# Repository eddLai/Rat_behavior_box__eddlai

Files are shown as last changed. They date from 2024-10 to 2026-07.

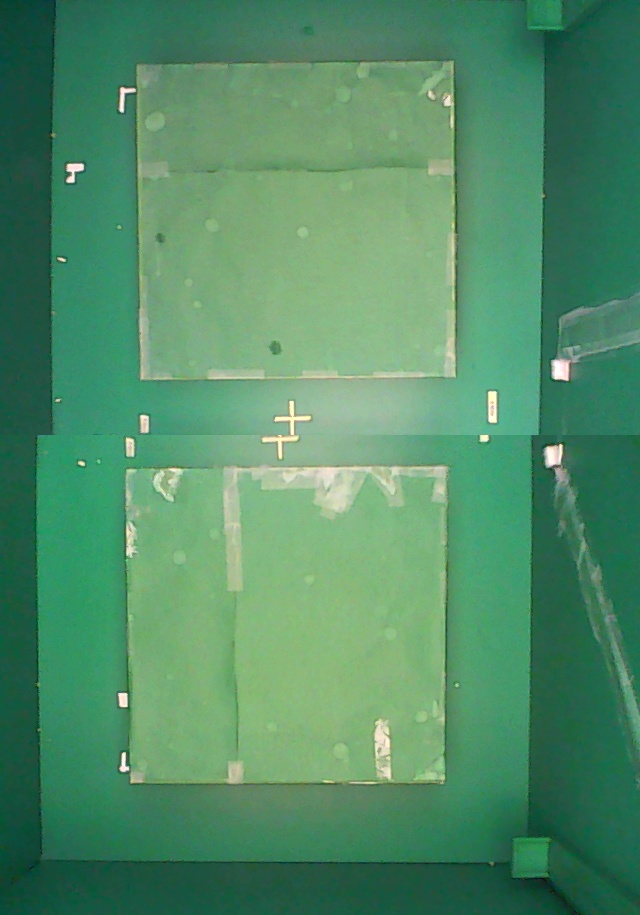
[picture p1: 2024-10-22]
python_to_detect_rat_at_point/baseline/82.jpg

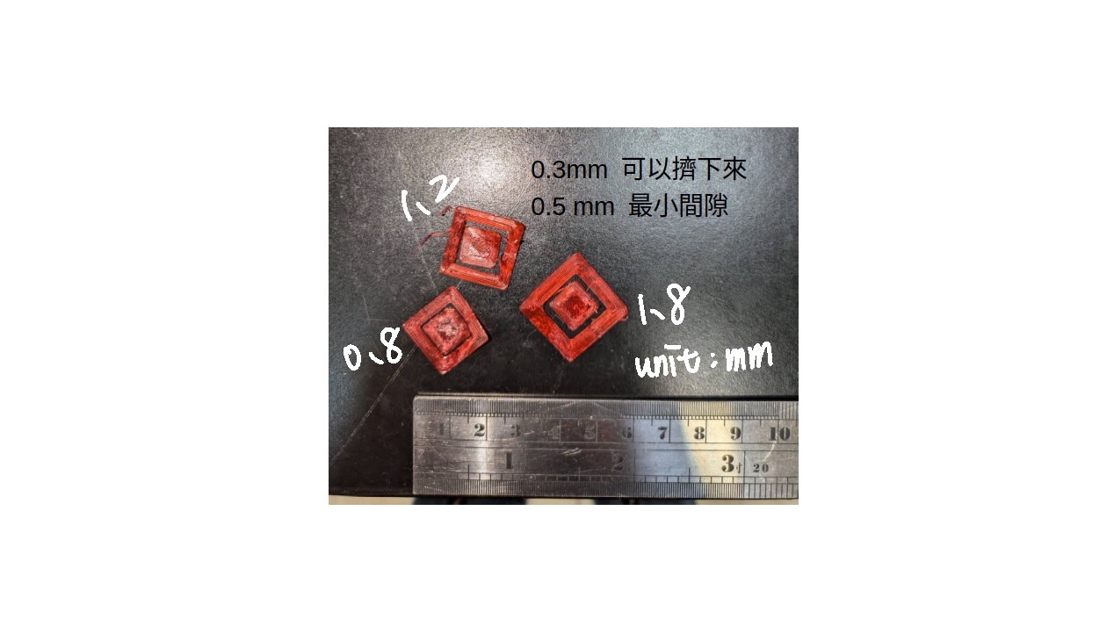
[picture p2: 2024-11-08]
behavior_box_3Dprint_models_eddlai/precision.jpg

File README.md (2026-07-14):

## Now Operating Version...
- **Arduino for Cue and Reward**: [`UART_left_right_dir_deter_v8.ino`](Arduino_UART_from_python/UART_left_right_dir_deter_v8/UART_left_right_dir_deter_v8.ino)
- **Camera for Rat Position**: [`python_to_detect_rat_at_point/two_camera_videos_diff_Uart_blah.py`](python_to_detect_rat_at_point/two_camera_videos_diff_Uart_blah.py)
---

# Arduino UART 版本演進說明

## 版本功能比較總表

| 版本 | 主要功能 | 獎勵控制方式 | LED閃爍方式 | 重要修正 |
|---|---|---|---|---|
| **v2** | 基礎左右/直立模式 | 繼電器 (relay) | 阻塞式 (blocking) | 基礎版本 |
| **v3** | 新增正確回應判斷 | 繼電器 (relay) | 阻塞式 (blocking) | 修正獎勵邏輯 |
| **v4** | 非阻塞式處理 | 繼電器 (relay) | 非阻塞式 (non-blocking) | 解決延遲問題 |
| **v5** | 伺服馬達版本 | 360伺服馬達 (servo) | 非阻塞式 (non-blocking) | 硬體更新 |
| **v6** | 純左右轉模式 | 360伺服馬達 (servo) | 非阻塞式 (non-blocking) | 移除模式選擇 |
| **v7** | 三向閥與純手動控制 | 180伺服馬達 (servo) | 非阻塞式 (non-blocking) | (1)平滑步進控制三向閥+齒輪開關 (2)新增修改起身模式、手動控制模式、排水模式 |
| **v8** | 新增長距離移動/純轉向模式 | 180伺服馬達 (servo) | 非阻塞式 (non-blocking) | (1)新增 Mode 5：碰 L/R 直接給水，黑點 `D` 作為 rearm 防重複 (2)全部字串改用 `F()` 巨集釋放 SRAM (3)記憶體不足，暫時註解停用 Mode 2 |

---

## 詳細版本說明

### v2 - 基礎版本
**檔案位置**: `Arduino_UART_from_python/UART_left_right_dir_deter_v2/`

**主要功能**:
- Mode 1: 攝影機偵測模式 (Camera detection mode) - 左右轉任務
- Mode 2: 站立模式 (Standup mode) - 隨機間隔給水 (20-35秒)

**硬體配置**:
- 獎勵控制: 繼電器 (reward_L: pin 6, reward_R: pin 7)
- LED: L1/L2 (pin 11/10), R1/R2 (pin 13/12)

**已知問題**:
- LED閃爍期間會阻塞其他指令處理
- 不論走對走錯都給水

**獨立衍生檔案**:
- `blah_altertime.ino`: 新增模式3 (固定時間間隔的站立模式)
- `blah_correct_reward.ino`: 新增正確回應判斷 (只有走對邊才給水)

---

### v3 - 正確回應判斷版本
**檔案位置**: `Arduino_UART_from_python/UART_left_right_dir_deter_v3/`

**新增功能**:
- Mode 1: 攝影機偵測模式 (Camera detection mode) - 左右轉任務
- Mode 2: 站立模式 (Standup mode) - 隨機間隔給水 (20-35秒)
- Mode 3: 固定時間間隔站立模式 (Standup fixed mode) - 可手動設定固定時間間隔給水
- ✅ 判斷大鼠是否走對邊，只有正確才給水
- ✅ 新增狀態變數: `isObstacle_L`, `isObstacle_R`, `taskInProgress`
- ✅ 新增獎勵時間控制: `reward_time = 3500ms`

**核心改進**:
- 接收 'L' 或 'R' 訊號時會檢查是否與任務方向 (`ans`) 一致
- 走錯邊會重置狀態但不給水
- 新增 `resetState()` 函數統一管理狀態重置

**仍存在的問題**:
- LED閃爍仍為阻塞式，可能導致指令延遲

---

### v4 - 非阻塞式處理版本
**檔案位置**: `Arduino_UART_from_python/UART_left_right_dir_deter_v4/`

**核心改進**:
- ✅ **非阻塞式LED閃爍**: 使用 `millis()` 和狀態機實現
- ✅ **訊號緩衝處理**: 即使在閃爍中也能立即處理指令
- ✅ 新增 `processResponse()` 函數獨立處理每個指令

**技術細節**:
```cpp
// 非阻塞閃爍相關變數
bool blinking = false;
unsigned long blinkLastToggle = 0;
int blinkCount = 0;
int blinkState = 0;
const int maxBlinks = 15;
```

**執行流程改善**:
1. `left_right()` 中先累積所有指令進 buffer
2. 使用 `processResponse()` 逐一處理
3. LED閃爍與指令處理並行，不會互相阻塞

**解決的問題**:
- ✅ 解決 "如果在紅點下待太久會出現觸發LED CUE錯誤的問題"
- ✅ 避免閃爍時 L/R 指令被讀走但無法處理

---

### v5 - 伺服馬達版本
**檔案位置**: `Arduino_UART_from_python/UART_left_right_dir_deter_v5/`

**硬體更新**:
- ✅ **獎勵系統**: 從繼電器改為伺服馬達 (因直流抽水馬達對電壓值敏感)
  - `reward_L`: Servo on pin 10 (角度 114° 給水, 90° 停止)
  - `reward_R`: Servo on pin 9 (角度 60° 給水, 90° 停止)
- ✅ **獎勵時間縮短**: `reward_time = 300ms` (v3/v4 為 3500ms)
- ✅ **LED pin腳調整**: L1/L2 (pin 12/13), R1/R2 (pin 6/7)

**Mode 3 功能更新**:
- Mode 3 改為手動控制LED測試模式
- 接收 '1' 指令: LED閃爍10秒
- 接收 '0' 指令: LED關閉

**程式碼變化**:
```cpp
// v4使用繼電器
digitalWrite(reward_L, LOW);  // 激活
digitalWrite(reward_L, HIGH); // 停止

// v5使用伺服馬達
reward_L.write(114);  // 激活
reward_L.write(90);   // 停止
```

---

### v6 - 純左右模式版本 (為排除 50Hz 雜訊)(但實測無效:P)
**檔案位置**: `Arduino_UART_from_python/UART_left_right_dir_deter_v6/`

**核心改進**:
- ✅ **移除模式選擇**: 開機自動進入 Mode 1（左右轉任務）
- ✅ **即插即用**: 按 reset 鍵或接上行動電源立即啟動
- ✅ **精簡程式碼**: 移除 Mode 2/3 相關程式碼
- ✅ **獨立供電友善**: 不需連接電腦選擇模式，適合使用行動電源

**使用情境**:
- Arduino 改用行動電源供電，避免電腦 USB 雜訊干擾
- 不需要透過 MobaXterm 選擇模式
- 專注於左右轉任務實驗

**與 v5 的差異**:
```cpp
// v5: 需要等待模式選擇
while (Serial.available() == 0) {
  // 等待用戶輸入 '1', '2', '3'
}

// v6: 直接啟動
Serial.println("Camera detection mode (left-right task) started automatically");
```

---

### v7 - 三向閥開關門與純手動控制版本
**檔案位置**: `Arduino_UART_from_python/UART_left_right_dir_deter_v7/`

**核心改進與硬體更新**:
- ✅ **180度三向門控制**: 取代原本的 360 度連續旋轉馬達，改用 180 度伺服馬達控制實體三向門 (`posClose = 0`, `posOpen = 180`)。
- ✅ **平滑步進控制 (`moveServoSmooth`)**: 為了減少機構震動與噪音，所有開關門動作皆改為每 10ms 移動 2 度的平滑步進，大幅提升硬體作動穩定性與動物實驗品質。
- ✅ **馬達防抖優化**: `attach()` 與 `detach()` 邏輯完美整合於模式切換與各功能中，並加入起訖點判斷，消除待機時的雜訊與抖動。
- ✅ **緊急停止 (`D`) 安全升級**: 收到 `D` 時，兩側門會平滑強制關閉，並確實重置當前位置記憶 (`currentPosL/R`)。

**重構&更新模式**:
- **Mode 1 (左右轉任務)**: 保留核心邏輯，走對邊時平滑開門給水後關門。
- **Mode 2 (自動站立)**: 移除水泵控制，改為僅開啟「右門」並維持 6 秒，隨機間隔 20~35 秒。
- **Mode 3 (改成手動控制開關)**: 徹底移除舊版不直覺的秒數輸入。改為「純手動發球機」：
  - 輸入 `1`: 右門打開，LED 持續閃爍 (給水)。
  - 輸入 `0`: 右門關閉，LED 立即熄滅。
- **Mode 4 (新增：Drain Mode)**: 實驗後的專屬管路清洗/排水模式。
  - 輸入 `O`: 雙門全開。
  - 輸入 `C`: 雙門關閉。
  - 提示可隨時重啟序列埠來回到主選單。

---

### v8 - 長距離移動模式與記憶體 (SRAM) 優化版本
**檔案位置**: `Arduino_UART_from_python/UART_left_right_dir_deter_v8/`

**核心改進**:
- ✅ **新增 Mode 5 (Long locomotion / pure turning)**: 適用於長距離移動與純轉向任務。
  - 碰到 `L` 點 → 平滑開左門給水後關門；碰到 `R` 點 → 平滑開右門給水後關門。
  - **與 Mode 1 的差異**: 不需 `M` 觸發、不指定方向、不判斷對錯 —— 碰到就給。
- ✅ **Mode 5 防重複機制 (`armed` 狀態鎖)**: 解決「老鼠只觸發一次，馬達卻反覆開關多次」的問題。
  - 根因：Python 端是逐幀送訊號，老鼠停在 L/R 點時會連續灌入大量 `L`/`R`，每個字元都觸發一次給水。
  - 解法：用單一共用鎖 `armed`。給一次水後立即上鎖 (`armed = false`)，阻塞給水期間湧入的重複訊號全部忽略；**必須走過任一黑點（收到 `D`）才重新武裝** (`armed = true`)，才能再給下一次。
  - 初始 `armed = true`，第一次碰 L/R 即給水。此設計逼老鼠實際跑完路線（黑點→L/R）才有獎勵，符合 locomotion 實驗本意。
  - Arduino 端相容既有 Python：三個黑點 (MD/LD/RD) 都送 `D`，任一個都可 rearm。
- ✅ **SRAM 記憶體優化（關鍵修正）**: 所有 `Serial.print/println` 字串改用 `F()` 巨集包裝。
  - 問題：加入 Mode 5 後全域變數用到 **2047/2048 bytes (99%)**，開機時 stack 與全域變數相撞 → **選單完全印不出來、系統無反應**。
  - 解法：`F("...")` 讓字串留在 Flash（32KB，充裕）而非複製到 SRAM（僅 2KB）。行為與輸出完全不變，只是搬移儲存位置。

**⚠️ Mode 2 (自動站立) 暫時停用**:
- 因 ATmega328P 的 SRAM 僅 2KB，為釋放記憶體空間，先將 `stand_up()` 函式及 `loop()` 內的 Mode 2 分支**註解掉**。
- 開機選單仍列出 `Enter '2'`，但該模式功能尚未啟用。

**Mode 對照表 (v8)**:
| Mode | 功能 | 說明 |
|---|---|---|
| 1 | 攝影機偵測（左右轉） | 需 `M` 觸發、判斷對錯，走對邊才給水 |
| 2 | ~~自動站立~~ | ⚠️ 暫時停用（記憶體不足） |
| 3 | 手動控制 | 輸入 `1` 開右門+閃燈、`0` 關門 |
| 4 | 排水 (Drain) | 輸入 `O` 雙門全開、`C` 雙門關閉 |
| 5 | 長距離移動 / 純轉向 | 碰 `L`/`R` 直接給水，黑點 `D` 作為 rearm |

---

# Others
3D tracker
- official doc when behavior box be setup: [[3DTracker Doc for v180924 (under refinement).pdf]]
- [3DTracker-FAB documentation — 3DTrackerFAB-doc documentation](https://3dtrackerfab.readthedocs.io/en/latest/)

---
# 《需求列表》

### 直立式給水器｛站立｝
1. 針對每次水量限制問題+鼠鼠會扒上去/電線被3D tracker抓到難濾掉的問題
  - sol1. 把馬達架高、深度變深、上面也要做高擋起來
2. 瀑布自助餐問題
  - sol2. 中繼出水孔（鼠鼠舔的地方）深度挖深一點（？）可以小小裝水、累積到某個水量再流掉
  - sol3. 換材質

3. 給水時間random除錯困難的問題
  - sol4. 新增輸入mode 2時間，改Arduino

### 掛勾式給水平台｛左右｝
1. 鼠鼠頭上線會勾到方形轉角的問題
  - sol5. 把平台改半圓（包含底部也是弧狀）
  - sol6. 把平台改高一點，增加鼠鼠底下通過空間
2. 鼠鼠選錯邊依舊會給reward的殘水問題
  - sol7. 直接改code，把紅點以外的其他點作為判斷是否走對邊的檢查點，判斷正確才出水
3. 出水針頭因為各種水壓阻塞底座不穩導致需一直調整的問題
  - sol8. 印一個針頭固定座

### 銅網上的線路
1. 線路時常接觸不良的問題
  - sol9. 焊起來一勞永逸（嗎
  - sol10. 應歪歪要求封裝起來
  - sol11. 更新乖乖、改善風水佈局
  - sol12. 3D列印鼠鼠女神像祭壇

### 其他
1. LED燈會不定時左右亂閃
  - sol13. 改善code
  - sol14. 買更多乖乖
2. 忘記這是指什麼了XD👇
  - 可以定義順序，改python

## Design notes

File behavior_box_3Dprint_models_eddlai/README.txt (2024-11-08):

我使用2020年買的ender 3S v2中國製列印機
tinmorry, yasin等中國耗材就夠用了
列印品質跟線材的濕度比較有關係。
PETG需要非常注意平台的調平，在列印的繞圈階段就要確認

├─Cura slicing setting
│      creality_base_extruder_0_petg_15may_tz
│      creality_ender3s1_petg_15may_tz
│      PETG setting.curaprofile
│      PLA setting.curaprofile
│
├─One-way Door and LED shell
│      Door holders RL.gcode
│      Door pillar.gcode
│      Door.gcode
│      Door_all.gcode
│      led shell and One-way Door.shapr
│      LED shell.gcode
│
└─Rat_watering_platform
    │  trunk v2.gcode
    │  wall.gcode
    │  water slide.gcode
    │  water supply platform v2.shapr
    │  water supply platform v2.stl
    │
    └─old version
            main water supply platform.gcode
            upper water supply platform.gcode
            WALL_water supply platform.gcode

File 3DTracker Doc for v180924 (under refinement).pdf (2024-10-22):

## 3DTrackerFAB documentation

3DTrackerFAB-doc
- 1. Hardware preparation
– | 1.1. Cameras
– | 1.2. Extension cables
– | 1.3. PC
– | 1.4. Camera mounting
- 2. Software preparation
– | 2.1. Installing 3rd party libraries
– | 2.2. Installing main programs of the 3DTracker-FAB
- 3. Calibrator and recorder usage
– | 3.1. Camera calibration using the Calibrator
– | 3.2. Recording 3D video using the Recorder
- 4. Preprocessor usage
- 5. Tracker usage
– | 5.1. Starting the Tracker
– | 5.2. Importing and setting parameters
– | 5.3. Fitting
– | 5.4. Saving and Exporting the fitting result
– | 5.5. Measurement tools
- 6. Other software usage
– | 6.1. Viewer
– | 6.2. Data analysis scripts (Python/MATLAB)
- 7. Trouble shooting
– | 7.1. Calibrator/Recorder does not start (with R200 cameras)
– | 7.2. Calibration does not work well
– | 7.3. Objects or animals are not captured
– | 7.4. Dropping frames during recording
– | 7.5. Menu bar invisible / mouse offset from view
- 8. Information for developers
– | 8.1. Preparing the development environment
– | 8.2. Programming Style
– | 8.3. More Information
- 9. Appendix
– 9.1. R200 camera mechanism

– | 9.2. Details of the parameters in the Tracker
– | 9.3. Output files
– | 9.4. Synchronizing with other systems
– | 9.5. Online tracking (under development)

## 3DTracker-FAB documentation¶

The document was written by Dr. Jumpei Matsumoto and Dr. Marcelo Aguilar-Rivera. We thank Dr. Laleh Quinn for her proof reading. This version is still under refinement.

## Introduction¶

The 3DTracker-FAB (for animal behavior) is an open source software for 3D-video based computerized behavioral analysis. The 3DTracker-FAB will help users acquire and analyze 3D trajectories of animal body parts, as shown below.

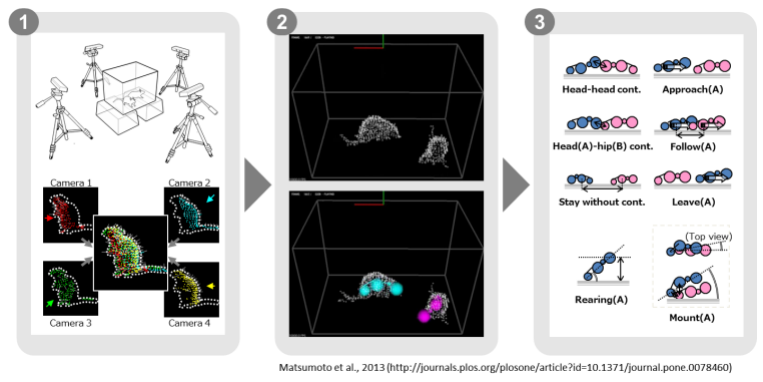
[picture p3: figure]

[Fig 0-1]

First, animals 3D imagines are reconstructed from depth cameras (~4) images (Fig 0, left). Second, body positions are estimated by fitting skeletal models to the 3D image (Fig 0, middle). Third, several behavioral parameters are calculated based on body part trajectories (Fig 0, right).

In the current workflow, a set of software modules are used. The images from multiple cameras are calibrated and recorded, with the “Calibrator” and “Recorder” modules respectively (Chapter 3). Then, the recorded images from different cameras are processed off-line for their integration into a full 3D image, down sampling, etc., with the “Preprocessor” module (Chapter 4). Then, the skeletal models are fitted to the 3D image, with the “Tracker” module (Chapter 5). Finally, the resultant 3D trajectories (csv file format) are analyzed with Python/MATLAB scripts (Chapter 6). The present version of the 3DTracker-FAB only supports the analysis of rats and mice. Other species could be supported in the future.

The 3DTracker-FAB is basically licensed under an MIT license. So, note that the software is provided “as is”, without warranty of any kind, express or implied.

### 1. Hardware preparation¶

### 1.1. Cameras¶

Multiple Intel Realsense R200 or D400 cameras (Fig 1-1) are required for recording with the 3DTracker system. These cameras are chosen because of their outstanding performance characterized by the lack of interference among cameras when multiple units are simultaneously capturing the same object (see Appendix for details of the camera). A R200 or D400 is composed of a color camera and a depth sensor to obtain RGB and depth images, respectively.

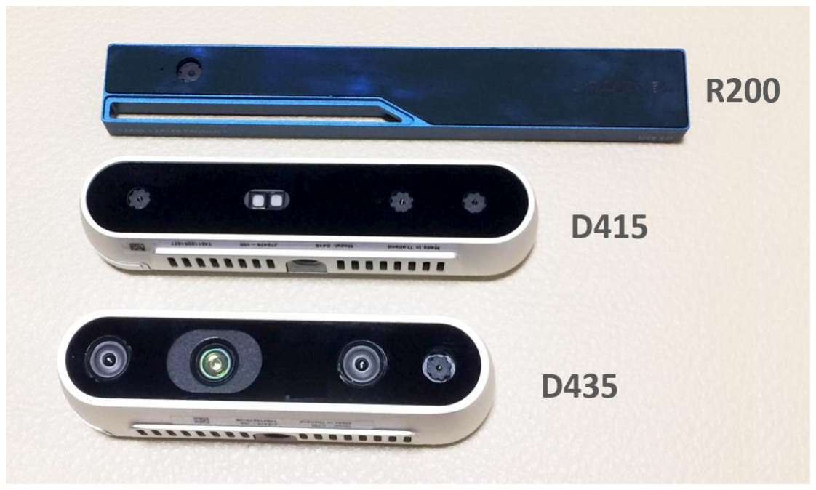
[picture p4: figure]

[Fig 1-1: Intel realsense cameras]

You can get R200 and D400 from the Intel website:

https://click.intel.com/realsense.html

D400 has two models: D415 and D435. The software supports both of them. For new users, we recommend using D400, because it is an improved version of R200. Both D435 and D415 are good enough for tracking with the present system. For the detailed comparison, see: https://realsense.intel.com/compare/

### 1.2. Extention cables¶

Given that the original USB 3.0 cable of the R200 or D400 is too short, it is necessary to extend it or to replace with a longer cable. We have confirmed the following extentions/cables work:

- For R200:
– UGREEN, USB 3.0 Active Extension Cable (https://www.amazon.com/dp/B01FQ88CE6)
- For D400:
– | Anker, PowerLine 10ft USB-C to USB 3.0 (https://www.anker.com/products/variant/powerline-10ft-usb-c-to-usb-3-0/A8167011)
– | NewNex, UL-A01C12-8M (https://www.newnex.com/usb-3-1-type-c-active-cable-legacy.php)

### 1.3. PC¶

The 3DTracker (except for MATLAB/Python scripts) runs only on Windows 10 (64-bit). The CPU does not need to be very fast. However, the number of cores (number of parallel processers) in the CPU should be more than the number of cameras used, because the Recorder software processes each camera data in parallel. In addition, a large HDD should be installed in the PC, because of the big size of 3D video. The PC monitor resolution should be more than 1280x1024. We have been recording from four cameras with a HP EliteDesk 800 G2 Core i7-6700 (3.4 GHz), 8GB RAM, 500 GB + 6TB HDD, and a power unit of 400W 80PLUS.

The camera uses almost the whole transmission bandwidth of an USB 3.0 port. So, more than one camera cannot be connected to the same USB controller. For this reason, we added three expansion cards
(https://www.amazon.co.jp/dp/B00B6ZCNGM) to get in total four USB controllers (including the one embedded in the mother board), thus having a camera connected per controller. The expansion cards have to be hooked to the PC power supply to feed enough power into the “active” USB extension cable, beside of be inserted in the mother board slots.

Note

We strongly recommend using the same components suggested above to get a high-quality signal. We have tried several different products and those previously described are the best ones based on our experience.

### 1.4. Camera mounts¶

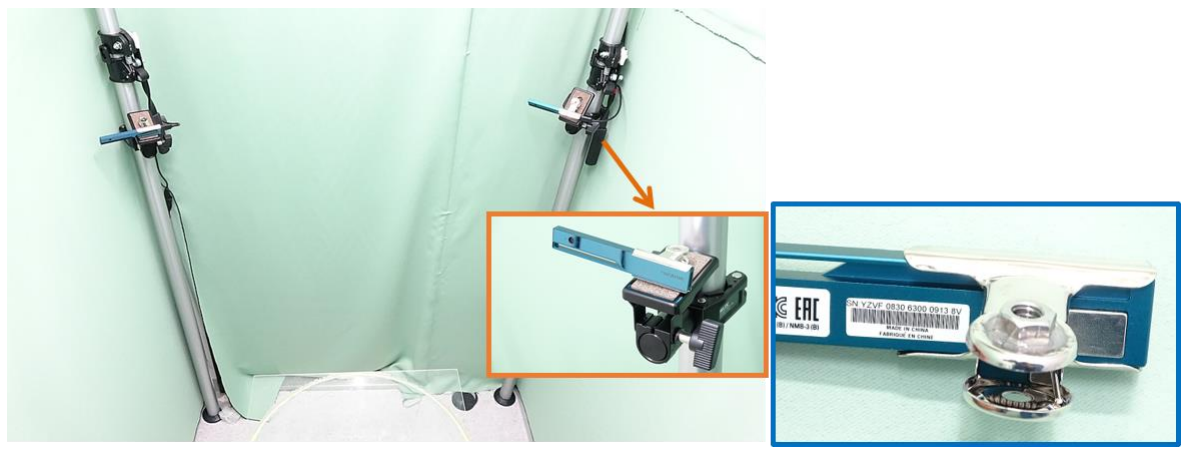
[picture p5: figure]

[Fig 1-2]

Example of four depth cameras setup. Each R200 camera was hooked to a post fixed to the floor and the ceiling (insert orange frame), through a custom adaptor made by gluing a 1/4-inch nut to a metal bulldog clip (insert blue frame). The main picture shows two of the four cameras.

Hint

The depth sensor of the camera measures the depth by emitting infrared (IR) light and capturing the IR reflection to objects (see Appendix for the detail of the mechanism of the camera). So, two cameras should not be placed face-to-face, to prevent the infrared sensor from saturating because of directly received infrared light from the other. Similarly, shiny surfaces should not be placed in front of a camera. Thus, we recommend placing the cameras slightly tilted downward from the horizontal plane. Also check the camera specification for 1) the minimum distance between the camera and objects for depth sensing (e.g., 40 cm for R200), and 2) the field of view. These constraints should be considered during camera setting.

### 2. Software preparation¶

### 2.1. Installing 3rd party libraries¶

The 3DTracker-FAB utilizes functions of many free software libraries. Please download and install the software below. You can download the software from our website at http://3dtracker.org/downloads.html

1. OpenCV 3.2.0 (library for image processing)
2. PCL 1.8.0 (library for point cloud processing)
3. Visual C++ 2015 redistributable (library for running the software that was written on Visual Studio C++ 2015)
4. Kinect for Windows Runtime v1.8 (library for Kinect v1 camera and backward compatibility)

Warning

DO NOT install the R200 driver provided by Intel because the 3DTracker doesn’t need it. Also, some users have reported that updating the R200 firmware could trigger the malfunctioning of the R200. See links below:

https://github.com/IntelRealSense/librealsense/issues/163https://github.com/IntelRealSense/librealsense/issues/429

After installing the libraries listed above, add the following folder to the environment variable “PATH”:

- C:\opencv320\build\x64\vc14\bin (change “C:\opencv320”, to your install directory)
- C:\Program Files\PCL 1.8.0\bin
- C:\Program Files\OpenNI2\Redist

See how to add directories to the “PATH”: https://www.computerhope.com/issues/ch000549.htm

### 2.2. Installing main programs of the 3DTracker-FAB¶

Download the prebuilt version of the 3DTracker-FAB from our website http://3dtracker.org/downloads.html

Uncompress the downloaded zip file. The extracted folder contains the software and data folder.

Hint

Because recorded data will be initially saved in the data folder, it is recommended to place the extracted data folder in a large HDD.

### 3. Calibrator and recorder usage¶

The Calibrator and the Recorder are modules for calibration and recording of the multiple-cameras setup of the 3DTracker system, respectively.

### 3.1. Camera calibration using the Calibrator¶

The video instruction: https://youtu.be/IE_ZDVuzYC8

Calibration for the relative positions of the cameras are necessary for integrating images captured by different cameras and then to re-construct a full 3D image. The Calibrator is a software wizard for the multi-camera calibration.

Connect the cameras to the PC and start Calibrator.exe. If Calibrator.exe doesn’t start, the cameras may have not been recognized (see Trouble shooting). In the start page (step 0) of this software wizard, you will see a 3D view display (center) where camera images are projected as a cloud of points, and a wizard window (bottom). In the 3D view, the red, green, and blue arrows correspond to X, Y, and Z axes, respectively. The 3D view can be controlled with the right button (R) dragging of a mouse, as follows: R + drag -> Rotate the view; R + drag + Ctrl key -> Zoom in and out; R + drag + Shift key -> translate the view. To discriminate clearly between the points from different cameras, you can color the points by enabling “Mark cameras with different colors” in the top left window. The 3D view can be switched to the 2D view where the image of each camera is shown, by clicking the “Switch to 2D” button on the top left window. Click “Next” in the wizard window to proceed to the next step.

In the step 1, move cameras to cover the space where you want to record while checking the 2D view. Also select the reference camera (the point clouds of the other camera will be aligned to the one of the reference camera). Note that in the 2D view, camera images are ordered in left-to-right and top-to-bottom according to the camera IDs.

In the following steps (2-6), the user scans the recording space with a light pointer and records the pointer track. Then, the software calculates the relative camera positions fitting the observed trajectories recorded from the different cameras during the calibration process (Fig 3-1, left). For the pointer we recommend using incandescent MAG-LITE (e.g., https://www.amazon.com/dp/B00002N9ET) in the candle mode, by removing the lid covering the light bulb (Fig 3-1, right)

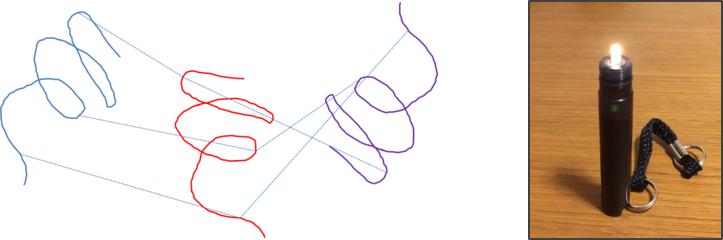
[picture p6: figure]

[Fig 3-1: left, schematic showing the mechanism. The lines with different colors represent the pointer trajectories observed simultaneously from 3 different cameras in this example; right, light pointer as a candle]

In the step 2, set the camera exposure for pointer tracking. Put the pointer in the recording space and turn off the room light. Then, set the exposure using the slider in the wizard window, to enhance the contrast between the pointer light and the background.

In the step 3, Set the brightness threshold for the pointer detection and tracking.

In the step 4, slowly move the pointer in the recording space to draw a trajectory for calibration (a spiral trajectory is recommended). Note that the pointer should be in view of all the cameras.

In the step 5, filter the trace (to remove some noise). You can use the temporal trimming and the outlier removal to remove the noise in the traces. For the detail of the parameters of the outlier removal, see: http://pointclouds.org/documentation/tutorials/statistical_outlier.php.

In the step 6, first, check if the point clouds from different cameras are perfectly aligned. To check the alignment, place some objects in front of the cameras and color the points by enabling “Mark cameras with different colors” in the top left window. Then, look at the corners and the overall shapes of the objects in the screen. If point clouds with different colors are not well aligned, go back to the previous steps and repeat the operation described above until a good result is achieved.

The calibration using the pointer is only for the relative positions among cameras. So, the absolute position of one of the cameras (the reference camera) should be input manually. Move the sliders in the wizard window to set the position and the rotation of the reference camera. Set X axis rotation, Y axis rotation, Z axis rotation, and translation. Rotation after translation makes it hard to adjust the position and rotation (see also the video link above). When you set the absolute position, make sure that the Y axis corresponds to the vertical axis, because the Tracker assumes it for fitting purposes.

Lastly, in the step 7, set the region of interest (ROI) with the sliders. You can also input the value directly by clicking + Ctrl key on slider. Then, click “Next” and “Save Config and Quit”, to finish the calibration.

### 3.2. Recording 3D video using the Recorder¶

Start Recorder.exe. Once the Recorder starts, the following screen will appear:

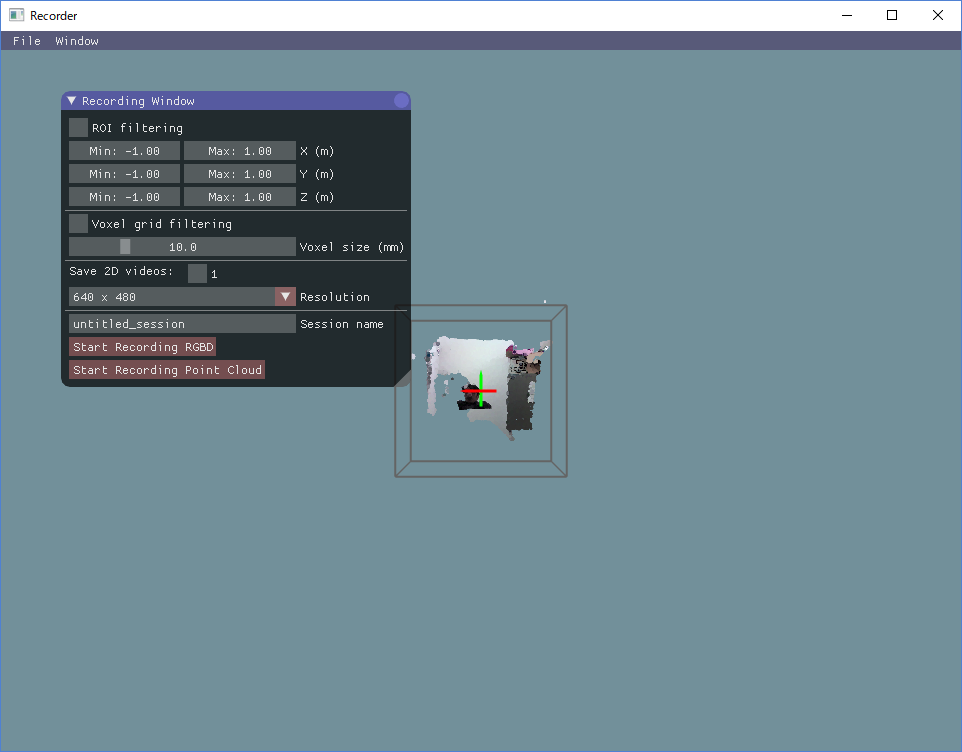
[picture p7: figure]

[Fig 3-2]

You will see a menu-bar, and a 3D view display which is same as the one in the Calibrator (see above). The various tool windows can be displayed from the menu tab > ‘Window’.

To start recording, in the “Recording window”, input the data file name in the “session name” text box and click “Start recording RGBD” or “Start Recording Point cloud” button. With “Start recording RGBD”, raw data consisting of RGB images and depth (D) images is stored. The size of the raw data is big (around 300 MB/camera/min). With “Start Recording Point cloud”, the point cloud data captured from the cameras are stored. Combined with the “ROI filtering” which removes the points outside the ROI, and “Voxel grid filtering” which down samples the points, the size of the point cloud data becomes much smaller than that of the raw RGBD data. Use 5 and 10 mm for the voxel size for the voxel grid filtering for mice and rats, respectively. By enabling the “save 2D videos” check boxes for the cameras, you can also save the 2D RGB video, which is useful for tracking (see Chapter 5), preliminary visual observation of behavior, etc. If you choose recording the raw data (RGBD), you can generate the 2D video offline. So, in this case, it is recommended not to check those boxes to reduce the computational load during recording.

Note

For D400 cameras, in addition to point cloud and RGBD file format, recording with rosbag file format (http://wiki.ros.org/rosbag) is also supported. Using the format, you can select higher spatial and temporal resolution, although the file size will be large (the compression algorithm in rosbag format is faster but less efficient than the one in RGBD format). Click “Start Recording Bag” in the “Recording window” for the rosbag recording. Before the preprocessing (Chapter 4), convert the rosbag to RGBD format, by using Rosbag2RGBD.exe.

After starting recording, 3D view is disabled and an RGB image is shown instead, reducing the computational load during recording. Click “Stop” button to stop recording. The recorded data is stored in the “data” folder containing the Recorder app (“Recorder.exe”) in the folder named as the “session name” that you have input before recording. See Chapter 9 for details about the output files.

### 4. Preprocessor usage¶

This module is for preprocessing the recorded data, for merging the 3D point clouds, down sampling (removing overlapping points) the data, calculating the surface normal vector at each point, etc. The preprocessing is necessary for pose estimation in the Tracker (Chapter 5). When you start the Preprocessor, it asks to select a folder to processes the session data in. If you select a folder containing multiple sub-folders from different sessions, the module will process the data in these sub-folders if they don’t contain additional sub-levels. This is because the app does not search more than one level below the folder selected. The data preprocessed previously is skipped by default. The Preprocessor is called from the command prompt, and the preprocessing parameters are set by command line. We have prepared the following batch files that call the Preprocessor with certain predefined parameters as follows:

- Preproc_rat.bat: Use this for rats (down sampling voxel size = 10 mm).
- Preproc_rat(f).bat: Same as the previous one but it does not skip the data already preprocessed.
- Preproc_mice.bat: Use this for mice (down sampling voxel size = 5 mm).
- Preproc_mice(f).bat: Same as Preproc_rat(f), but for mice.

Example of a command line (Advanced):

> preprocessor.exe -f -2dvid -vsize 0.01 -camuse 0011

- -f: no skip for the data preprocessed previously
- -2dvid: generate 2D video files from RGBD data
- -vsize: down sampling voxel size (in meters)
- -camuse: selects cameras for the merging of the point clouds. 0=not use, 1=use.

In the example above, the merging points cloud is generated by using images from the camera #3 and #4.

### 5. Tracker usage¶

### 5.1. Starting the Tracker¶

Start the Tracker and select the xml file in the data folder that you want to analyze. Then, the following screen will appear.

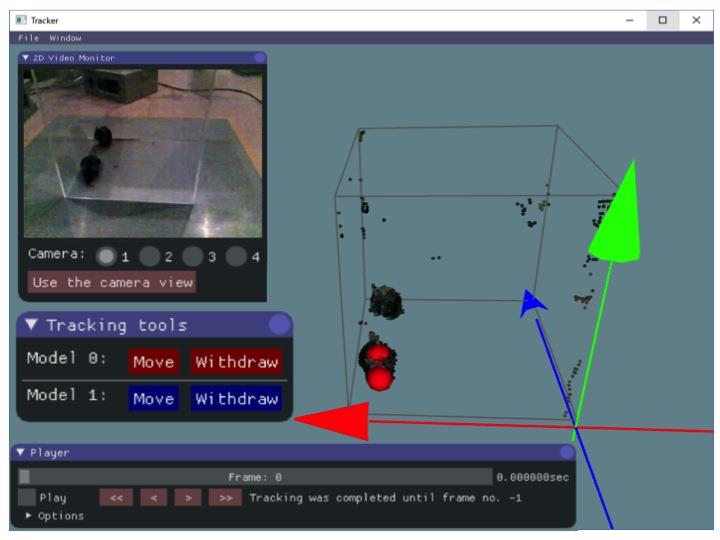
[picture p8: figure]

[Fig 5-1]

The windows on the screen are those you can launch by clicking the tabs in the menu Window. In addition, the skeletal models represented by connected spheres are shown in the Tracker screen. The 3D view can be controlled with the right button (R) by dragging the mouse as follows: R drag -> Rotate the view; R drag + Ctrl key -> Zoom in and out; R drag + Shift key -> translate the view.

The following “Player window” is used for searching a video frame and fitting execution.

[Fig 5-2]

The numbers inside, and at the right side of the top slide bar, indicate the current # of the video frame and time, respectively. You can move the slide bar to search a specific video frame. By checking the box “Play” you can start the playback. The fitting of the skeleton models for pose estimation during playback is for the frames where it was not estimated. For the frames where it has already been estimated, the result of fitting is shown. The progress during the fitting process is displayed as “Tracking that has been completed…”. When starting the fitting process, you have to do it from the first frame and then continue with the next one. DO NOT skip frames during the fitting since it can result in an irreversible corrupted physic simulation.

### 5.2. Importing and setting parameters¶

Before starting the fitting, you need to set some parameters for the process. The default parameters (e.g., dimensions of a skeletal model) are optimized for rats. So, to analyze mice, import predefined parameters for mice (e.g., Track_params_mouse_v20171104.xml) from “File Menu > Import params”. The parameters can be displayed and modified with the “Model Editor window”, “Physics sim params window”, “ROI setting window”, and “Color filter window”.

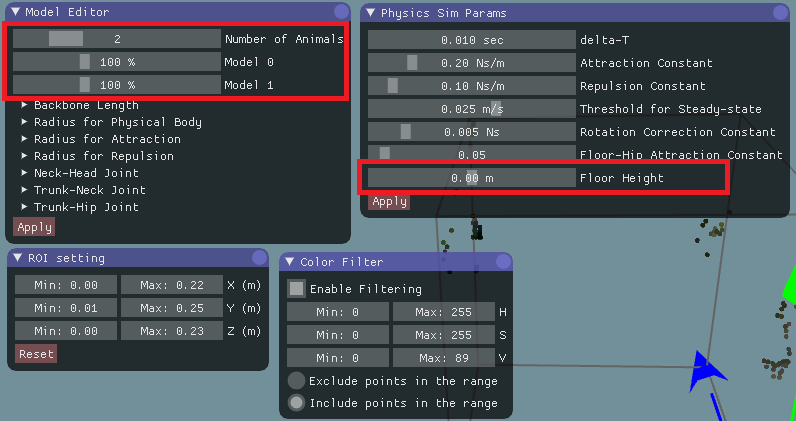
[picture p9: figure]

[Fig 5-3]

The “Model Editor window” is for the skeletal models. The slider on the top defines the number of animals (skeletal models). The scale of an animal can change depending on its age, sex, etc. So, you may need to change the scales using the other sliders in the red rectangle as shown in Fig 5-3. Detailed parameters outside the red rectangle (e.g., “Backbone Length”, “Radius for Physical Body”, etc.) don’t need to be changed frequently. After changing the parameters in the “Model Editor window”, click “Apply” button on the bottom, to apply the change.

The “Physics sim params window” is to parametrize the fitting algorithms, and usually it is necessary to change just some of them. The value of the “floor height” should be set to the height of the floor where the animal is standing in the global coordinate system. This parameter is important to constrain the movement of the model. The details of the parameters mentioned above are described in Chapter 9.

“ROI setting window” and “Color filter window” can be used to remove the points of non-animal objects. Removing such points will help fitting the skeleton models to the points cloud. In the color filtering, set the range of colors to include/exclude in the HSV color space (https://en.wikipedia.org/wiki/HSL_and_HSV). These parameters could be repeatedly used for the same experimental setup regarding rodent strain, age, apparatus, etc. You can re-use the parameters by exporting and then importing them from the “File menu > Export params” and “File menu > import params”, respectively.

### 5.3. Fitting¶

After the parameters have been set, start the fitting. Note that you cannot change the parameters during the fitting, otherwise the fitting will be re-initialized. In the first frame, manually set the initial position of the skeletal models. With shift key pressed, click two points from hip to head. You will see a line like the one in the figure below.

[Fig 5-4]

If it is hard to know the direction of the subject in a 3D view, try using “2D video monitor window” as shown in Fig 5-1. Then, click the “Move” button in “Tracking tools window” to change the skeleton model to the correct place (Fig 5-5).

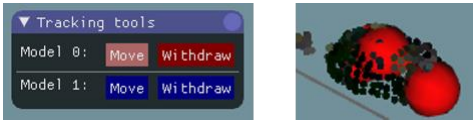
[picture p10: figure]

[Fig 5-5]

The model is automatically fit from the initial position. If you find that the model was not fitted properly, manually adjust it by dragging body parts (sphere) of the model with the left mouse button. After placing the skeleton models, start the fitting process by enabling the “Play” check box in the “Player window”. The positions shown during the play are the result of the fitting process. As the fitting progresses, when you find an error in fitting, such as when a big part of a model is outside the 3D image, reversed direction, or swapping between animals (Fig 5-6), pause the fitting by disabling the “Play” check box.

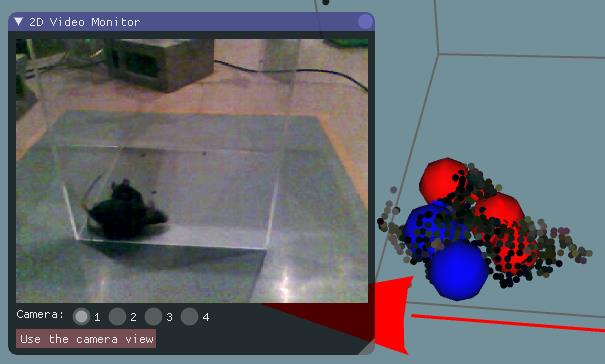
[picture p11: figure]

[Fig 5-6: an example of swapping error]

Then, by clicking “<<”, “<”, “>”, and “>>” buttons in the “Player window”, go back to the frame when the models start to get the error (Fig 5-7, middle). Then, manually adjust the models by dragging body parts (Fig 5-7, right) and re-start fitting from that frame by enabling “Play” check box.

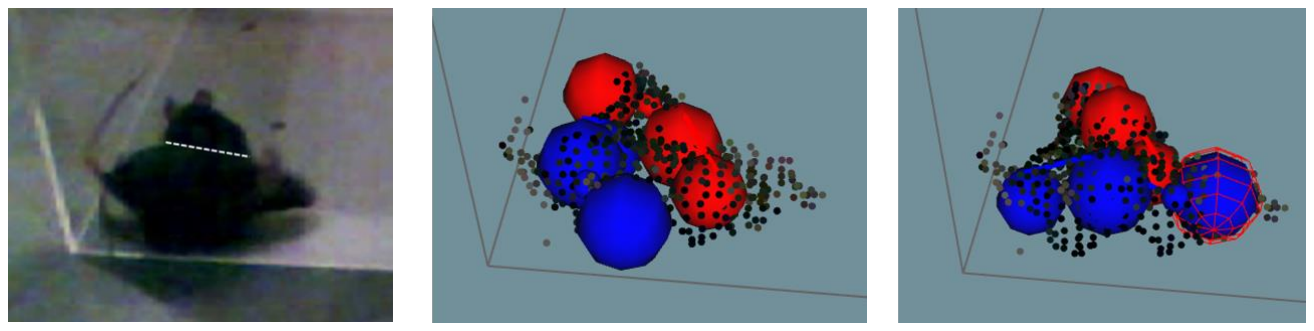
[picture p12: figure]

[Fig 5-7: correction of the swapping error shown in Fig. 5-6. Left: Actual mice positions, middle: before correction, right: after correction.]

If you find an error again, pause and fix it following the instructions described above. Repeat it and then progress with the fitting up to the last frames.

Hint

The Tracker has many functions to support this semi-automatic fitting process:

- The speed of playback can be changed in “Option” in the “Player window”.
- “Play” check box can be switched by pressing the space key.
- By rotating the mouse wheel during the video pausing you can change the video frame.
- By rotating the mouse wheel during playback it changes the playback speed.

Note

The fitting process must be done without skipping frames to get a successful result. Even if you don’t have an animal in the first frame, start from the first frame and not from the frame when the animal appears. For the fitting during the absence of animals, you can withdraw the model with “Withdraw” button in “Tracking tools window”. Note that the fitting process will be skipped if you move the frame using the slider on the top of the “Player window” or “<<”, “<”, “>”, or “>>” button below. When you restart the fitting after the manual correction, make sure that it restarts from the frame that you have corrected (check the progress of fitting in “Tracking has been completed…” display).

### 5.4. Saving and Exporting the fitting result¶

Once you have finished the fitting, you can re-check the result by playback or moving the slider in the “Player window”. The fitting result won’t be changed just by replaying the frames. You can save the fitting result from “File menu > Save result”. The result will be automatically loaded the next time you open the data. You can also reset the results to the one saved last time from “File menu > Load result”. This save/load function is also useful to interrupt the work. For the data analysis on the trajectories

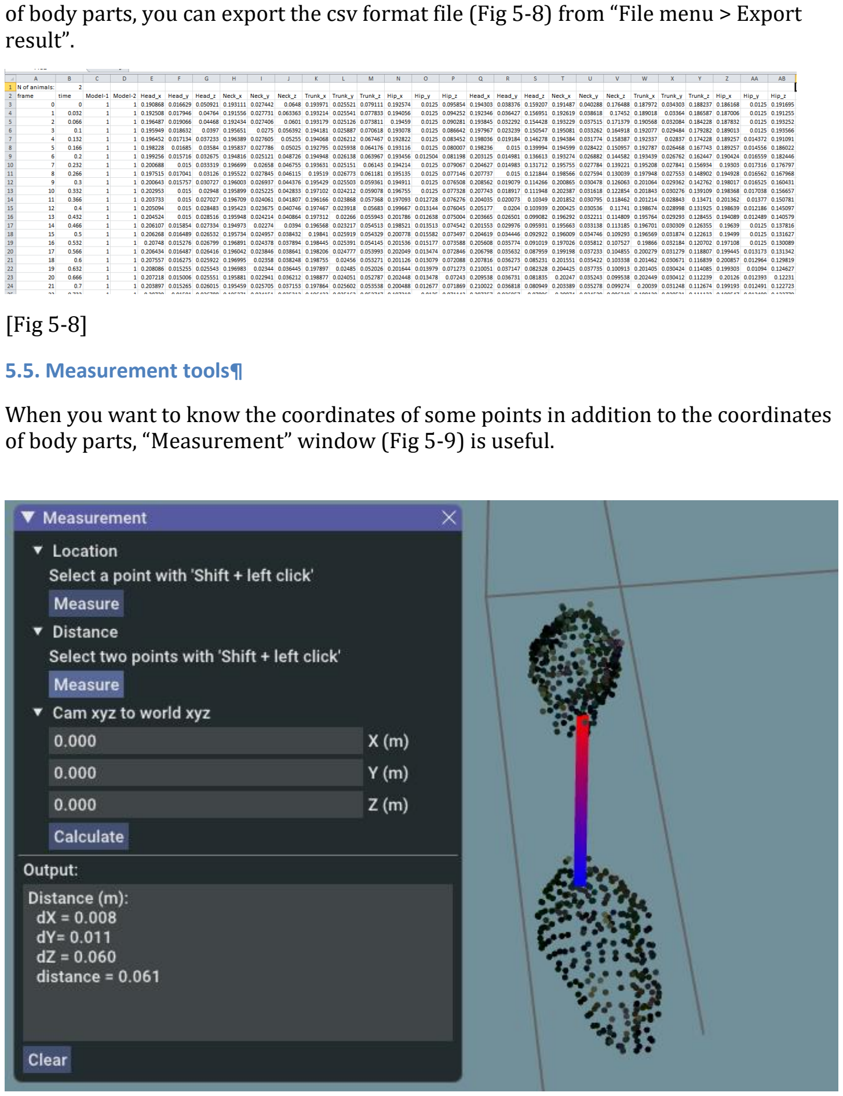
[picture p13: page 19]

of body parts, you can export the csv format file (Fig 5-8) from “File menu > Export result”.

[Fig 5-8]

### 5.5. Measurement tools¶

When you want to know the coordinates of some points in addition to the coordinates of body parts, “Measurement” window (Fig 5-9) is useful.

[Fig 5-9: Measurement tools. In this example, the distance between manually selected two points (a nose of a mouse and a hip of another mice) is calculated.]

The tool can be used to estimate three types of data: (1) location, this is the coordinate of a selected point, (2) distance between two selected points, and (3) an absolute coordinate converted from a relative coordinate to a camera.

For (1) and (2), select point(s) and click the “Measure” button, then the result will appear in the “Output” text box.

For (3), input the relative coordinate in the text boxes and click the “Calculate” button, then the result will appear in the “Output” text box. This function is useful, for example, when you want to know the coordinate of another sensor (microphone, high-speed camera, 4K camera, etc) mounted on the 3D cameras. If you input (X, Y, Z) = (0, 0, 0), you can also know the camera positions.

### 6. Other software usage¶

### 6.1. Viewer¶

The software can be used as a viewer to check the recorded data but without the fitting functions. To open the data in the Viewer, no pre-processing is necessary.

### 6.2. Data analysis scripts (Python / MATLAB)¶

We provide Python and MATLAB scripts for various processing with the trajectory data (csv file) and raw 3D video data (point cloud data, RGBD data) in the following site:

https://github.com/ThreeD-Tracker-FAB/3DTrackerFAB-script

We also encourage people to share their own scripts. You can do it through our github site, the forum (https://groups.google.com/forum/#!forum/3dtracker) or by contacting us through the form for such purpose (http://3dtracker.org/contact.html). If you have a useful code you would like to share, please let us know!

### 7. Trouble shooting¶

If you cannot find a specific topic associated to the 3DTracker or the solution for some related issue, ask your question in our forum (https://groups.google.com/forum/#!forum/3dtracker).

### 7.1. Calibrator/Recorder does not start (with R200 cameras)¶

The camera may not be recognized by the PC. Rule out any possible issue associated with cables between the PC and the camera. Check the connectors at the camera is not damaged.

Re-check the connection of the camera according to Chapter 2. If the problem persists, check whether the camera is listed in the “Device manager” (Fig 7-1).

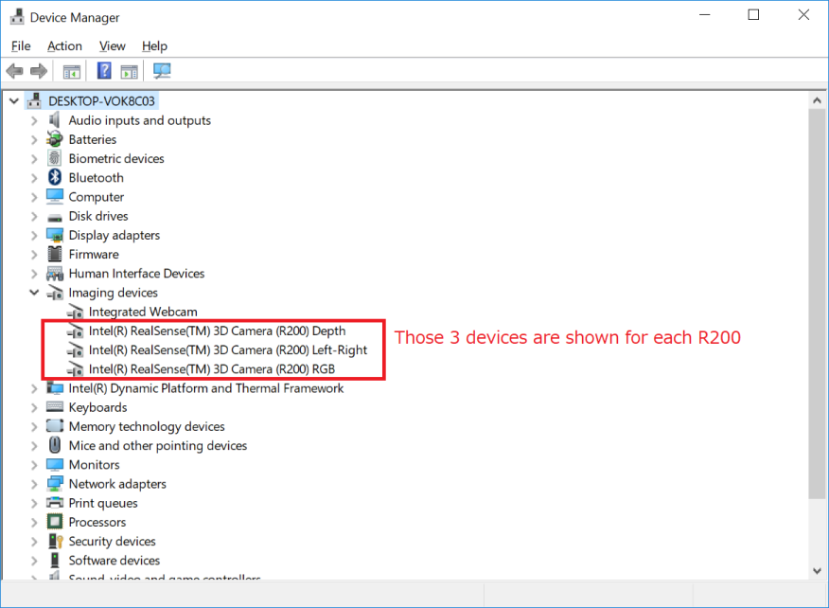
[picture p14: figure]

[Fig 7-1]

If the camera is not listed, make sure that “USB selective suspend” is disabled (https://www.techsupportalert.com/content/how-fix-annoying-windows-usb-problem.htm). (https://www.techsupportalert.com/content/how-fix-annoying-windows-usb-problem.htm) If the camera is listed but the problem persists, uninstall the device of RGB camera and re-install it by clicking “scan for hardware changes” icon (Fig 7-2). It has been reported that an RGB camera driver error happens after “Windows 10 Creators Update”, and the steps above fix the problem. (https://github.com/IntelRealSense/librealsense/issues/481).

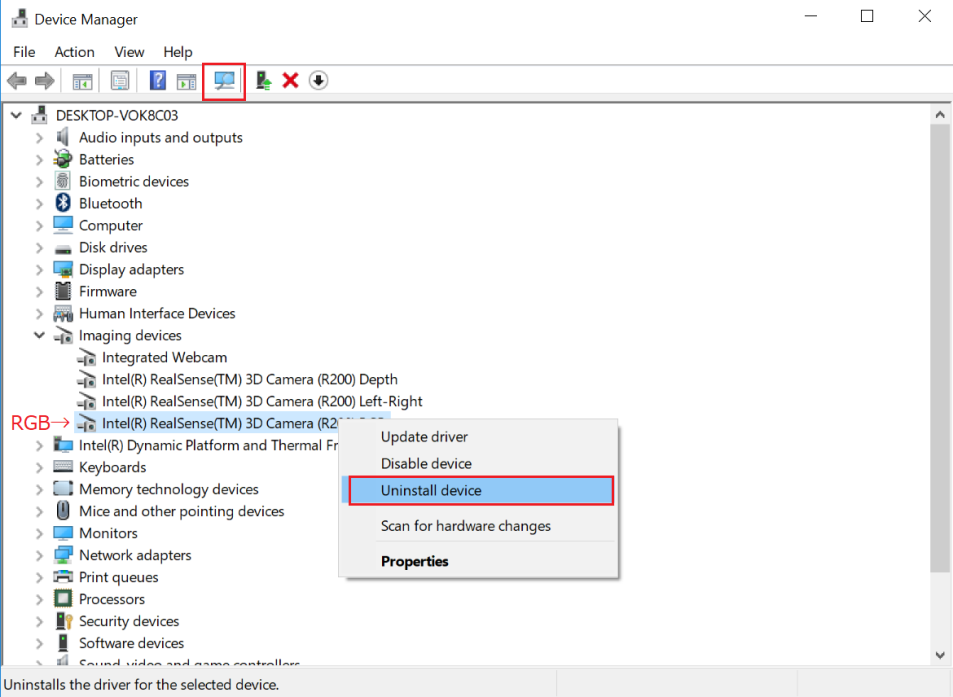
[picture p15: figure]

[Fig 7-2]

### 7.2. Calibration does not work well¶

We suggest trying the following:

- Check the area to scan with the pointer. In the 2D view of the Calibrator make sure the pointer is always inside the view of all the cameras, and the distance between pointer and cameras is always more than the minimum distance for the depth sensing of the camera (e.g., 40 cm for R200). Also make sure the pointer light is not strongly reflected by the floor or other objects.

### 7.3. Objects or animals are not captured¶

- Change the infrared (IR) gain. If the camera is too close to the surface recorded or number of cameras is big, the IR reflection become too strong saturating the IR sensor. The data in the saturated part will be lost, interfering the pointer tracking during the calibration. Reduce “IR camera gain” in “Camera setting window” to avoid the saturation (see also Appendix for the camera mechanism).
- Check the color of the object. Surfaces without IR reflection cannot be captured well (e.g., deep black colored plastic). In the case you need to consider changing the color of the object. Black fur mice (e.g., C57BL/6) can be captured without any problem.

### 7.4. Dropping frames during recording¶

Before you buy a faster PC, try the following:

- Wait long enough after the PC boots (PC is often slow just after boot).

- Change Windows setting to reduce the computational load for the other processes running in parallel (e.g., https://www.cnet.com/how-to/easy-ways-to-speed-up-windows-10/). (https://www.cnet.com/how-to/easy-ways-to-speed-up-windows-10/)

### 7.5. Menu bar invisible / mouse offset from view¶

The problem can happen with some old drivers of Intel HD Graphics video card (https://developer.blender.org/T51521). Update the driver.

### 8. Information for developers¶

### 8.1. Preparing the development environment¶

Use Visual Studio 2017 for the IDE.

First, download and install following libraries (You can download from our website at http://3dtracker.org/downloads.html):

1. OpenCV 3.2.0 (library for image processing)
2. PCL 1.8.0 (library for point cloud processing)
3. Kinect for Windows SDK v1.8 (library for Kinect v1 camera and backward compatibility)
4. 3DTracker Developer Tools (= librealsense, intel R200 camera library; Bullet physics, physics simulation library; freeglut, free opengl utility toolkit)
5. librealsense 2 SDK (library for using intel D400 camera)
6. (optional) NIDAQmx (National Instrument device library; used for TTL signal)

Second, add the following folder to the environment variable “PATH”:

- C:\Program Files\3DTrackerDevTools\bin
- C:\opencv320\build\x64\vc14\bin
- C:\Program Files\PCL 1.8.0\bin
- C:\Program Files\OpenNI2\Redist

### 8.2. Programming Style¶

For this, follow this link: https://google.github.io/styleguide/cppguide.html

### 8.3. More Information¶

Contact us through the forum (https://groups.google.com/forum/#!forum/3dtracker).

### 9. Appendix¶

### 9.1. R200 camera mechanism¶

Intel realsense R200 contains one RGB camera, two IR cameras, and one IR emitter. The IR emitter projects a random IR pattern to the objects (Fig 9-1, upper pictures). Distances from the camera to the objects’ surface are calculated using two IR camera images based on binocular disparity. As a result, a depth image (Fig 9-1, bottom picture), where each pixel in the image represents distance from the camera to the object surface, is generated.

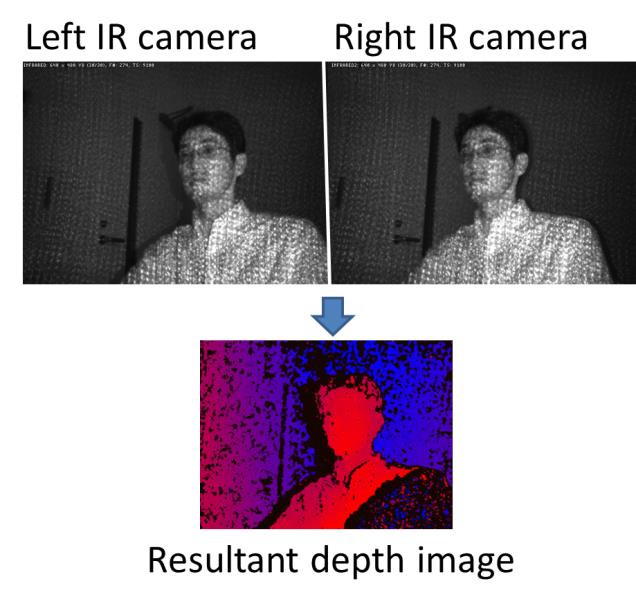
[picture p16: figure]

[Fig 9-1]

In 3DTracker software, a colored 3D point cloud is generated from the depth image and the RGB image captured by R200. Because R200 uses binocular disparity, the R200 cameras do not interfere each other. This is an excellent feature of R200 compared to the other 3D cameras (for example, ToF cameras, like Kinect v2) that severely interfere with each other. Although the R200 can work well in a multi-camera setup, if many of them are recording an object closely, the R200 would receive too much IR light causing some saturation (red circle in Fig 9-2).

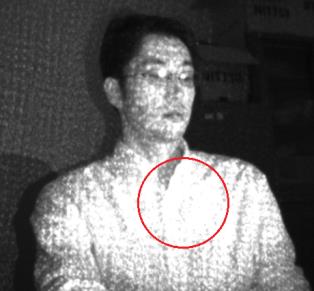
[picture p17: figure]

[Fig 9-2]

There is no binocular disparity in the saturated area, so the depth of the area cannot be calculated. By reducing the IR camera gain (in “Camera setting window” of the Recorder app), the saturation can be avoided. For the details of R200, see the Intel datasheet:
https://www.intel.com/content/dam/support/us/en/documents/emerging-technologies/intel-realsense-technology/realsense-camera-r200-datasheet.pdf (https://www.intel.com/content/dam/support/us/en/documents/emerging-technologies/intel-realsense-technology/realsense-camera-r200-datasheet.pdf)

### 9.2. Details of the parameters in the Tracker¶

For reference see Matsumoto et al., 2013: http://journals.plos.org/plosone/article?id=10.1371/journal.pone.0078460

### 9.3. Output files¶

The data of a recording session is saved as multiple files in the same folder. Each of the files contains data of different type and/or camera, as follows:

- [Session_name].metadata.xml: metadata file, which stores recording configurations.
- [Session_name].2dvideo.[N].avi: 2D RGB video of camera no. N.
- [Session_name].camintrin.[N].bin: internal parameter of camera no. N.
- [Session_name].rgbd.frame.[N].bin: RGBD data of camera no. N.
- [Session_name].rgbd.ts.[N].txt: the timestamp of the RGBD data
- [Session_name].pc.frame.[N].bin: Point cloud data of camera no. N.
- [Session_name].pc.ts.[N].txt: the timestamp of the point cloud data
- [Session_name].mrgpc.frame.bin: Merged point cloud data generated by Preprocessor
- [Session_name].mrgpc.ts.txt: the timestamp of the merged point cloud data
- [Session_name].trackparam.txt: Tracker parameters
- [Session_name].trackresult.bin: Tracker result

### 9.4. Synchronizing with other systems¶

To synchronize the 3D video recording with other data acquisition systems such as an ephys recording system, you can use the Recorder_TTL.exe. Specifically, the app has the following functions:

- TTL (5V) signal output at each video frame acquisition.
- Starting and stopping recording by TTL trigger inputs.

Hardware and software preparation before using the Recorder_TTL.exe:

1. Prepare a National Instrument DIO device (e.g., USB-6501)

2. Install NIDAQmx software (driver of National Instrument devices; you can find a link in http://3dtracker.org/downloads.html)
3. Connect the DIO device to the PC and set the device name as “Dev_3DT” (Fig 9-3) using NI MAX software.
4. The pins P0.0, P1.0 and P1.1 of the DIO device are for the video frame acquisition timing (output), starting recording and stopping recording (input), respectively. Connect the pins (and the ground pin of the DIO device) to appropriate pins of the other systems (e.g., the frame timing pin to a digital input of a data acquisition system).

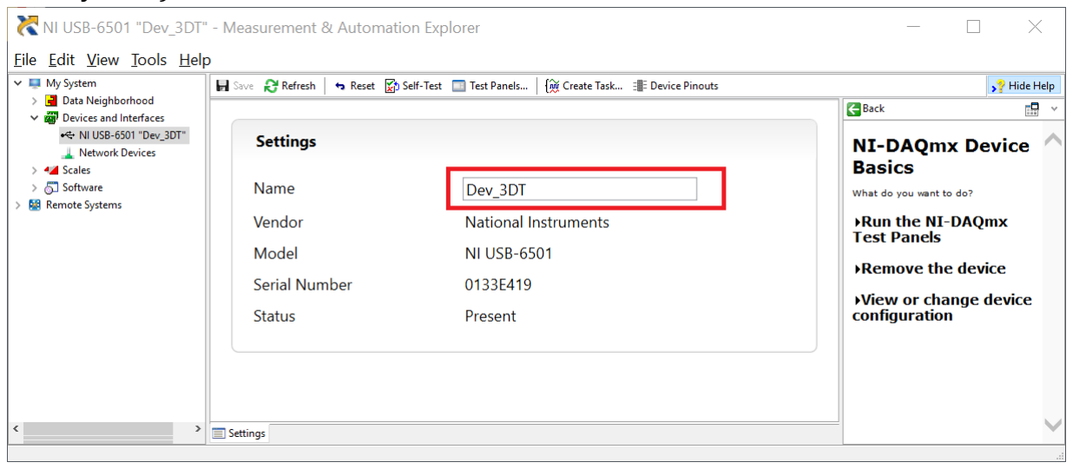
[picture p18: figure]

[Fig 9-3]

In Recorder_TTL.exe, check “Trigger Recording by TTL” in the “Recording Window”, to enable triggering recording by the TTL inputs.

During the recording, at each video frame acquisition, the output pin voltage flips transiently from 0 to 5 V and 5 to 0 V. Thus, each of the 5 V onsets and offsets corresponds to a frame acquisition timing (Fig 9-4).

[Fig 9-4: the relation between frame acquisition timings (arrows) and the output pin voltage]

Note

The USB data transmission from the camera involves the compression of the data, thus it has a delay (usually 100 - 300 ms). So, the TTL timing (when the PC acquires a video frame) is the actual frame capture timing + the delay. Each user has to measure and correct the delay of the camera. For example, capture an Arduino blinking its LED in front of the camera while the LED pin is also connected to a digital input of a data acquisition system. Then measure the delay, by comparing the timing of the TTL signal of the video frame with the LED onset and the timing of the LED pin signal. Repeat this to estimate the average delay.

### 9.5. Online tracking (under development)¶

The Tracker can also work in online, directly using the data streaming from the cameras. For the online tracking, connect the cameras to the PC and run Calibrator.exe to calibrate (if calibration has not been done). Then, run Tracker_online_mode.bat.

Date last modified: 2018.10.31

© Copyright 2017-2018, Jumpei Matsumoto, Marcelo Aguilar-Rivera, et al..

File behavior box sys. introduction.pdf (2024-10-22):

Introduction

Arduino 水泵系統（圖一）。Mode1 為左右選擇行為實驗，需要兩台額外相機支 持；Mode2 則為隨機起身實驗。

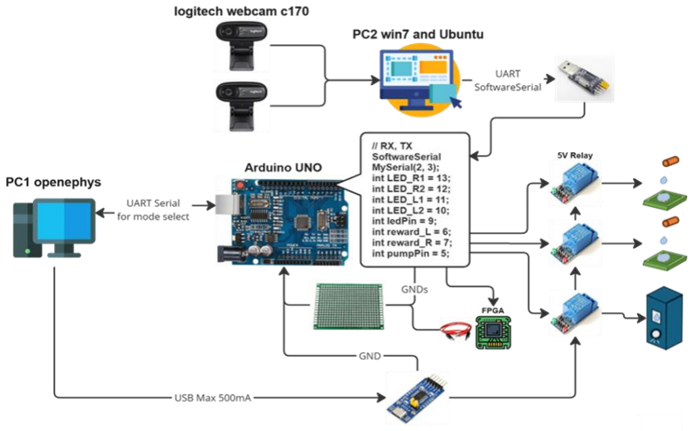
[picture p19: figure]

圖片連結 (https://miro.com/welcomeonboard/TElhRFBLaEVXM0tqY3prM0NhblNZVHFheWE0MjBLajlTNFduZW53Z09NTXZPRUprNFcxNGMweDJnZWhwR2xYQXwzNDU4NzY0NTc0OTA5NzMzNTQ4fDI=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)

操作流程：

1. 開啟兩台電腦。
2. 在 PC1 上找到 CH340 Serial，使用串口工具，輸入 1 或者 2。
3. if 切換模式: 按下紅色 reset 按鈕（圖二），重複步驟 2。

圖一. Arduino 水泵系統圖

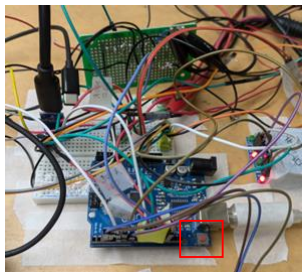
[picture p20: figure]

圖二. Reset 按鍵位置

4. 在 PC2 上找到（圖三）資料夾，右鍵以程式運行.sh 檔案即可進入（圖 四），若需要重新拍攝 baseline 請刪除 pkl 檔案。

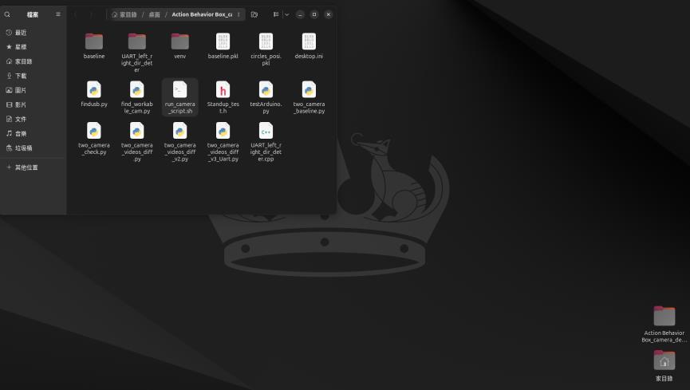
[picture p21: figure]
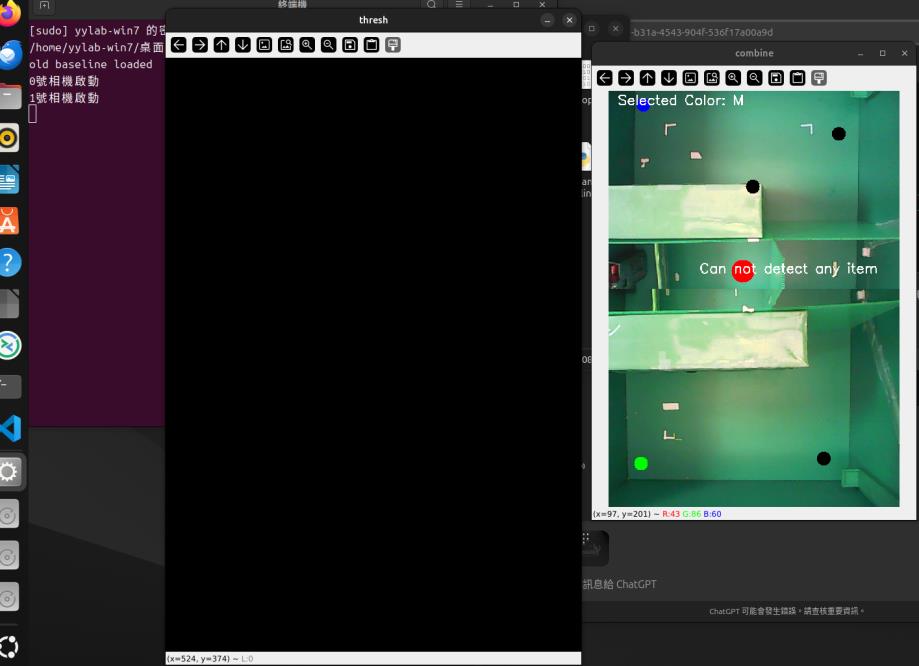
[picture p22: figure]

5. 若要調整圖四圓圈位置，請按下 WS 鍵，並直接使用鼠標點擊畫面。

圖三. PC2 Ubuntu 桌面

圖四. 偵測畫面

Specification

- 水泵規格（圖五）。
- 由於 PC2 電腦老舊因此在其上運行 Ubuntu24.04，用以支援 python3。
- Arduino pin 腳最大輸出為 200mA，因此使用 Relay 是必要的。
- Relay 的 IN，HIGH 為關閉。
- 洞洞板上似乎蠻容易氧化因此地線連接失敗。
- PC1 記憶體不太夠用，注意工作管理員。

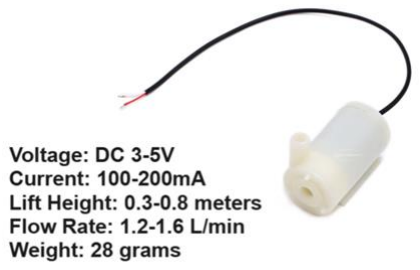
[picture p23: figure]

圖五. 水泵規格

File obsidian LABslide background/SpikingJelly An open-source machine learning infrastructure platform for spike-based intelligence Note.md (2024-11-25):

<style>
    .reveal {
        font-family: 'Times New Roman', '標楷體', serif;
        font-size: 30px;
        text-align: left;
        color: black;
        background-image: url('NTKLab_white bg.png');
        background-size: cover;
        background-position: center;
    }
	.with-border{
		border: 1px solid red;
	}
</style>

<grid drag="70 10" drop="-3 40">
SpikingJelly An open-source machine learning infrastructure platform for spike-based intelligence
<!-- element style="font-size: 40px;align: left; text-align: left;color: white"-->
</grid>

<!-- slide bg="NTKLab_white bg_cover_resize.png"-->

---
ref.
- [[SpikingJelly An open-source machine learning infrastructure platform for spike-based intelligence.pdf]]
- [Official doc](https://spikingjelly.readthedocs.io/zh-cn/latest/)

Terms:
- paradigm
 - Ecological niche 在軟體界的應用優勢與定位
 - varieble attribute
 - FPTT(forward propagation through time), BPTT

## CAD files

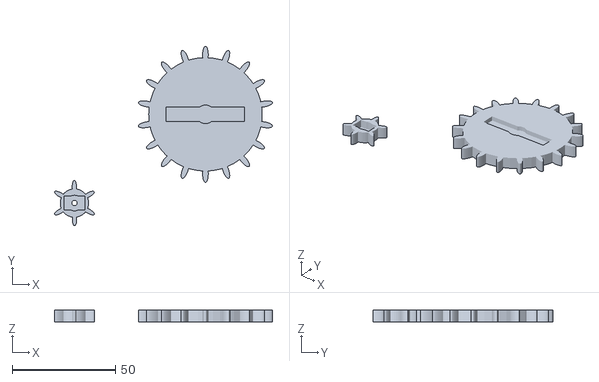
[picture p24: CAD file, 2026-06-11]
behavior_box_3Dprint_Gear_Jack/Copy of Gear.stl
105.7 x 87.0 x 5.97

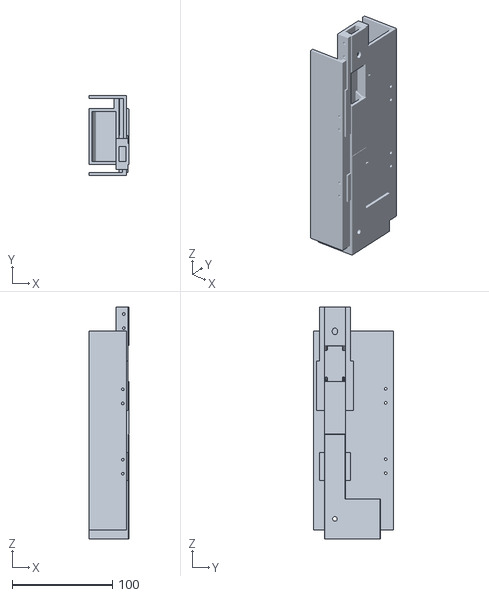
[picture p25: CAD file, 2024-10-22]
behavior_box_3Dprint_models_eddlai/Rat_watering_platform/water supply platform v2.stl
39.5 x 80.0 x 231.0

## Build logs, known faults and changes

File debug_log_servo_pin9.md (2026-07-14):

# Debug 紀錄：reward_R (pin9) 伺服不會動

> 目的：記錄所有已做過的測試與結論，避免鬼打牆。每做一步就回來更新。
> 最後更新：2026-06-22
> **狀態：✅ 已解決**（根因 = R 伺服自身 GND 地線裂焊；解法 = 把 R 伺服 GND 直接拉到 Arduino 空的 GND 腳，繞過裂焊。見 T18 / §3 / §6）

---

## 0. 系統與症狀

**系統**
- Arduino（Uno/Nano, ATmega328P）跑 [UART_left_right_dir_deter_v7.ino](../Arduino_UART_from_python/UART_left_right_dir_deter_v7/UART_left_right_dir_deter_v7.ino)
- 2× **MG90S 金屬齒**伺服當三向給水閥：
  - `reward_L` → **pin10**（正常）
  - `reward_R` → **pin9**（異常）
- 伺服電源：**外部 5V**（powerbank→TTL 輸出），經洞洞板，各自焊出 VCC/GND
- 訊號線：Arduino pin → 伺服訊號腳

**症狀**
- `reward_R`(pin9) 伺服**不會轉**（卡住嗡嗡叫 / 或無反應）。
- `reward_L`(pin10) **正常**。
- 兩路差異：只差「Arduino 的腳」和「中間的線路」。

---

## 1. 已做過的測試與結果

| # | 測試 | 結果 | 推論 |
|---|---|---|---|
| T1 | 換一顆**新伺服**到 pin9 | 反應一模一樣（不轉） | 不是這顆伺服 |
| T2 | 把壞那顆拿到**另一台 Arduino** 用簡易碼跑 | **正常轉動** | 伺服本體沒問題 |
| T3 | 伺服**從機構上拆下空轉**測 | 一樣不轉 | 與三向閥/齒輪機構無關 |
| T4 | 運轉時量伺服接頭 **VCC–GND** | 穩定 **5V** | 電源到伺服 OK |
| T5 | 量伺服接頭 **GND ↔ 共地 GND** 連通 | 蜂鳴器響（且焊點 AB 膠封死） | 共地 OK |
| T6 | pin10(L) 那路 | 正常 | 反證：Arduino GND 確實與伺服共地（否則 L 也不會動） |
| T7 | 訊號線從 pin9→pin4（v7 改 attach(4)，manual mode 按1） | 「靜靜待著」沒動 | ⚠️ 無效測試：v7 manual mode 內部又 attach(9)，且伺服未必插在被驅動的腳 |
| T8 | 用乾淨 sweep sketch 測 pin 4/6/9/11 | 無反應、訊號對 GND 無電壓；但 pin10 會動 | ⚠️ 當時「伺服訊號線沒插到被驅動的那支腳」/ 線是斷的 |
| T9 | **發現訊號線是斷的**：舊線量不到電壓 → **換新單心線** | 腳對 GND 出現正常 **0.2~0.5V 跳動** | ✅ 找到並修掉一個真故障（斷線） |
| T10 | 換新線後，量**伺服接頭**：VCC–GND=5V、訊號–GND=0.2~0.5V 跳動 | 數值正常，但**伺服仍不動** | 訊號/電源/地在伺服端都「測得到」，卻不轉 |
| T11 | 把 **R 的訊號線接到 pin10**（與 L 並接） | **連 L 也不動了！** | 🔴 **重大突破**：正常高阻抗訊號線不可能拖垮 pin10 → **R 訊號路徑某處短路/漏電到 GND**，把驅動腳拉垮。解釋了 pin9 只量到 0.3V 殘值、伺服收不到完整脈衝 |
| T12 | 把 R 訊號線從 pin10 **拔掉** | **L 仍然不動（沒恢復）** | ⚠️ 當時推測 pin10 被燒壞——**後來證實是假警報**（見 T13） |
| T13 | 重測 pin10 + reward_L | **又會動了！** | 🟢 **翻盤**：之前 L 不動的真正原因是 **powerbank 關掉了、伺服根本沒供電**。→ T11/T12 的「短路 / pin10 燒壞」結論**全部失效**，是 powerbank 沒開造成的假象 |
| T14 | 對 pin9 / pin10 / 對照腳做**靜態拉 High**（非 PWM），量腳↔GND | **全部 ≈5V** | ✅ **沒有任何腳燒掉**，pin9、pin10 都健康。reward_R 不動跟 Arduino 腳無關 |
| T15 | **交叉測試**（最關鍵）：① **原 Arduino** 控 pin9 訊號 + **另一塊 Arduino** 供 5V/GND；② **另一塊 Arduino** 控 pin9 訊號 + **原 powerbank** 供 5V | ① **會動** ✅ ② **不會動** ❌ | 🎯 **破案**：唯一跟成敗相關的變數是**電源**。用別的電源就會動 → 故障在 **powerbank → R 伺服這條供電/接地路徑**。①同時證明原 Arduino pin9 訊號 OK、R 伺服本體 OK |
| T16 | 用原 powerbank 供電時，量 R 伺服接頭 VCC↔GND | **仍有 5V，但伺服不動** | ⚠️ 不矛盾：5V 是「伺服自己 VCC↔GND」（兩腳都來自 powerbank），**證明不了伺服 GND 有跟 Arduino 共地**。最可能是 **R 那支的 powerbank-GND↔Arduino-GND 共地斷/虛接** → 伺服有電卻讀不懂訊號（次因：VCC 焊點虛接，待機量 5V、出力時塌壓） |
| T17 | **斷電**蜂鳴反覆量地線網路（同樣兩點、隔幾分鐘量兩次） | 4 條裡 3 條翻面；且出現 **A↔B 通、A↔C 通、但 B↔C 不通** 的自我矛盾 | 🔴 **實錘 intermittent 裂焊**：A=B、A=C ⟹ B=C 是靜態電路鐵律，量到 B≠C 表示接點在量測的幾秒間就忽通忽斷。→ 任何單次通斷讀數都不可信，逐點追是無底洞 |
| T18 | **把 R 伺服 GND 直接拉一條新線到 Arduino 空的 GND 腳**（繞過 R 自身那段裂焊地線） | ✅ **馬達立刻會動** | 🎯🎯 **結案**：根因 = **R 伺服自身的 GND 地線（焊到洞洞板那段）裂焊**。新線繞過它，一次補上①訊號共地 ②回流路徑（Arduino GND 本就連到 powerbank GND，即 L 一直能動的同一條路）→ 迴路閉合，R 轉動 |

---

## 2. 已排除（高信心）

- ❌ **伺服本體**：T1（換新一樣壞）+ T2（壞的拿去別台會動）+ T15①（換電源就會動）
- ❌ **機構（三向閥/齒輪）**：T3（空轉測）
- ❌ **Arduino pin9 / pin10**：T14 靜態拉 High 全部 ≈5V，沒有腳燒掉
- ❌ **原 Arduino pin9 訊號**：T15① 用原 Arduino 控訊號就會動
- ❌ **共地（整體）**：T5 + T6 + L 正常
- ❌ **純軟體 bug**：軟體問題會讓兩側都壞，但 pin10/L 正常
- ✅ **已定位真因**：**R 伺服自身 GND 地線裂焊**（T18 拉新線繞過就會動）
- 🟢 **已推翻的舊結論**：T11「R 訊號短路」、T12「pin10 燒壞」——powerbank 沒開造成的假象（T13）；舊 §3「powerbank↔Arduino 共地斷」——T17 intermittent 假讀數誤導，真因在 R 尾線地

---

## 3. 根因（✅ 已確認，T18 結案）

🎯🎯 **R 伺服自身的 GND 地線（從伺服尾線焊到洞洞板那一段）是裂焊（intermittent）**，導致 R 的地時通時斷。
- 後果一（回流）：R 吃 powerbank 的 5V，電流要回 powerbank GND；地線裂焊 → 迴路時斷 → 沒電流 → 不轉。
- 後果二（訊號參考）：R 的 GND 飄 → 伺服讀 PWM 沒有穩定共同基準 → 讀到垃圾。
- 這完美解釋了 T16「量到 5V 卻不動」（5V 是 powerbank 自參考，跟「地通不通」無關）與 T17「量測自我矛盾/不可重現」（裂焊接點忽通忽斷）。

**為什麼 L 一直好、R 一直壞**：L 的地線那段焊點剛好咬得住、R 那段裂了。Arduino GND ↔ powerbank GND 這條共地是通的（L 靠它運作），所以 R GND 只要接到 Arduino GND 就同時拿到「共地 + 回 powerbank 的路」。

> 註：先前 §3 舊版推測「powerbank-GND↔Arduino-GND 共地斷」是被 T17 那些 intermittent 假讀數誤導，實際斷點在 **R 伺服自己的尾線地**。保留此註以免重蹈。

---

## 4. 定位斷點用的測試（已執行，留存供日後參考；結論見 T17/T18）
> 下列 C/D/E 是當時用來定位斷點的測試。實際上 E 量到的是 intermittent 假讀數（T17），最後靠 T18「直接拉新線繞過就會動」確認真因。日後再遇供電/接地問題可重用這幾招。

### ✅ 測試 C（最直接、只用電壓）：量「共地」是否斷
正常接法（powerbank 供電 + 原 Arduino 訊號），**通電**，量 **R 伺服 GND 腳 ↔ 原 Arduino GND 腳**：
- **= 0V** → 有共地（問題偏向 VCC 虛接，做測試 D）
- **不是 0V（浮動）** → 🎯 **共地斷了，就是這個**

### ✅ 測試 D（查 VCC 虛接）：帶負載量電壓
下指令叫 R 動的**當下**（伺服在吃電流時），量 R 伺服接頭 VCC↔GND：
- 待機 5V、**一動就掉到 3V 以下** → VCC 焊點虛接。

### ✅ 測試 E（斷電量通斷，定位斷點）
Arduino 拔線、powerbank 關，蜂鳴/電阻檔：
- powerbank 5V輸出 ↔ R 伺服 VCC 腳：應 ~0Ω
- powerbank GND輸出 ↔ R 伺服 GND 腳：應 ~0Ω
- powerbank GND ↔ Arduino GND（共地）：應 ~0Ω
→ 哪條「不通」就是斷點。

---

## 5. 重要方法論（避免再鬼打牆）

1. **程式 `SERVO_PIN` 必須等於「伺服訊號線實際插的那支腳」**，否則一定測不出。
2. **三用電表量 PWM 只有平均值**（0.2~0.5V 是正常），**看不出脈衝振幅/品質**。要查振幅用「靜態拉 High」測試。
3. **不要用 v7 / manual mode 測 pin 腳**：v7 多處散落 `attach(9)`，manual mode 只驅動 reward_R，會互相干擾。診斷一律用乾淨的 [servo_sweep_pintest.ino](../Arduino_UART_from_python/motor_test/servo_sweep_pintest/servo_sweep_pintest.ino)。
4. 用「**會動 / 不會動**」的二元測試（測試 A）優先於需要解讀數字的測試。
5. **「量到 5V 卻不動」一點都不矛盾**（T16 的核心教訓，務必記住）：
   - **電表量電壓幾乎不吃電流**（內阻 ~10MΩ）。所以就算 VCC 焊點裂到只剩高電阻，伺服**待機**(~10mA)時電表照樣讀到 5V；但伺服一**出力**(~300mA)就被那個爛焊點吃掉電壓 → brown-out 不動。比喻：快斷的吸管不喝時「水壓滿滿」，真的吸卻只剩一滴。→ 要查 VCC 虛接,得在**伺服出力的當下帶負載量電壓**,看會不會塌。
   - **量到的 5V 是「伺服自己 VCC↔GND」,兩腳都來自 powerbank,自成一個參考系**。它**證明不了伺服的 GND 有跟 Arduino 共地**。若共地斷了,伺服有 5V 電、卻是拿「自己浮動的地」去讀那個「相對 Arduino 地」的 PWM → 沒有共同基準 → 讀到垃圾 → 不動。→ 要查共地,得量**伺服 GND 腳 ↔ Arduino GND 腳**(通電量電壓應=0V,或斷電量通斷)。
   - 一句話:**伺服端 VCC↔GND 有 5V，只代表「powerbank 把 5V 送到了那兩腳」，不代表「能出力」也不代表「跟訊號共地」。** 這就是本案 R 故障(VCC 虛接 + 共地斷)被電表讀數誤導的根源。
6. **通斷/電阻只能「斷電」量**，通電量到的全是被真實電壓干擾的假數據（本案 Set 1 通電量 vs Set 2 斷電量結果相反，差點被帶歪）。且要量在**源頭裸金屬**（剝皮線芯/端子），別量在 AB 膠封死的點。
7. **自我矛盾 / 不可重現的通斷讀數 = intermittent 裂焊的鐵證**（T17：A↔B 通、A↔C 通、卻 B↔C 不通，靜態電路不可能）。遇到這種就**別再逐點追**（無底洞），直接判定接點裂焊、重拉乾淨線繞過。用 **wiggle test**（撥動線看讀數跳不跳）快速確認 intermittent。
8. **電流一定要繞一圈回到它的電源**：伺服吃 powerbank 的電，電流就**必須回得到 powerbank GND** 才成迴路。Arduino GND 腳能當回流點，只因它接得到 powerbank GND（它是中繼，不是終點）。診斷供電不通時，先問「電流回得去電源嗎」。

---

## 6. 修復（✅ 已實施，T18）
**核心：故障在 R 伺服自身地線的手焊裂焊段，不是 Arduino、不是訊號線、不是伺服。**

**已做的解法（會動了）**：
- 把 **R 伺服 GND 直接拉一條新線到 Arduino 空的 GND 腳**，繞過裂掉的舊地線。一條線同時補上「訊號共地」+「回流路徑」→ R 轉動。
- **為什麼一條線就夠**：電流要繞一圈回它的電源(powerbank)。Arduino 所有 GND 腳內部相通，且 Arduino GND 本就連到 powerbank GND（L 靠的同一條路）→ `R GND → Arduino GND → powerbank GND` 迴路閉合。Arduino GND 腳是「中繼站」，能用是因為它接得到 powerbank GND。

**長久穩定建議（optional，看要不要一勞永逸）**：
- 現在 R 的回流仍**借道那個 powerbank↔Arduino 的裂焊點**——它現在通、但哪天再裂 R/L 會再罷工。要根治可**補一條實線 `powerbank GND ── 主控 Arduino GND`**，把這個中繼也變成不裂的實線。
- **更乾淨的接地拓樸（star ground）**：共同點選 **powerbank GND**（或端子台），`R 伺服 GND → powerbank GND`（粗線、走回流，不經過 Arduino）、`主控 Arduino GND → powerbank GND`（訊號參考、幾乎不過電流）。避免伺服大電流穿過 Arduino 地造成雜訊。若跑實驗時 Arduino 不會抖/重啟，現狀也可接受。
- **新線一定要做應力釋放**（束線帶固定），否則它會變成下一個被扯裂的接點。
- 共地參考必須是**送 pin9 訊號的那顆 Arduino**，不能用別塊板子的 GND。
- **不需要**：換板、換伺服、改 v7 腳號、動訊號線（pin9 與訊號都已證實 OK）。
- **長遠**：powerbank 供電全面改成接線端子 + 應力釋放，淘汰 AB 膠封死的手焊點；考慮換穩定 5V 電源（powerbank 可能有低載自動斷電）。

**驗收標準**：斷電量共地三點(powerbank GND / Arduino GND / R GND)兩兩 ~0Ω 且 wiggle 撥線不跳；通電量兩兩 ≈0V；連續跑幾輪完整實驗 R 每次都穩定動作。

---

## !!! 筆記 !!!
### 一個核心觀念:電流一定要「繞一圈回到它的電源」
馬達的電是 **powerbank** 給的。所以馬達要轉,電流必須走完一個完整迴路:
```
powerbank 5V → 馬達 → 馬達GND →（某條路）→ 回到 powerbank GND
```
重點在最後那一步:**電流最終一定要回到 powerbank 的 GND** (因為電是它出的)。Arduino 的 GND 腳**本身不是終點**,它只是一個「中繼站」。

你把馬達 GND 接到 Arduino 空的 GND 腳會動,是因為:
- Arduino 板上**所有 GND 腳內部都是相通的**,而且
- 你的 **Arduino GND 又有連到 powerbank GND** (這也是 reward_L 一直能動的同一條路)

所以電流走: ```馬達GND → Arduino GND腳 → Arduino內部地 → (接點) → powerbank GND,繞回 powerbank 了 → 馬達轉```。

換句話說:不是 Arduino GND 腳有什麼魔力,是它「接得到 powerbank GND」。如果哪天 Arduino 跟 powerbank 完全沒共地,你接再多空的 Arduino GND 腳,馬達一樣不會動(電流回不去 powerbank)。

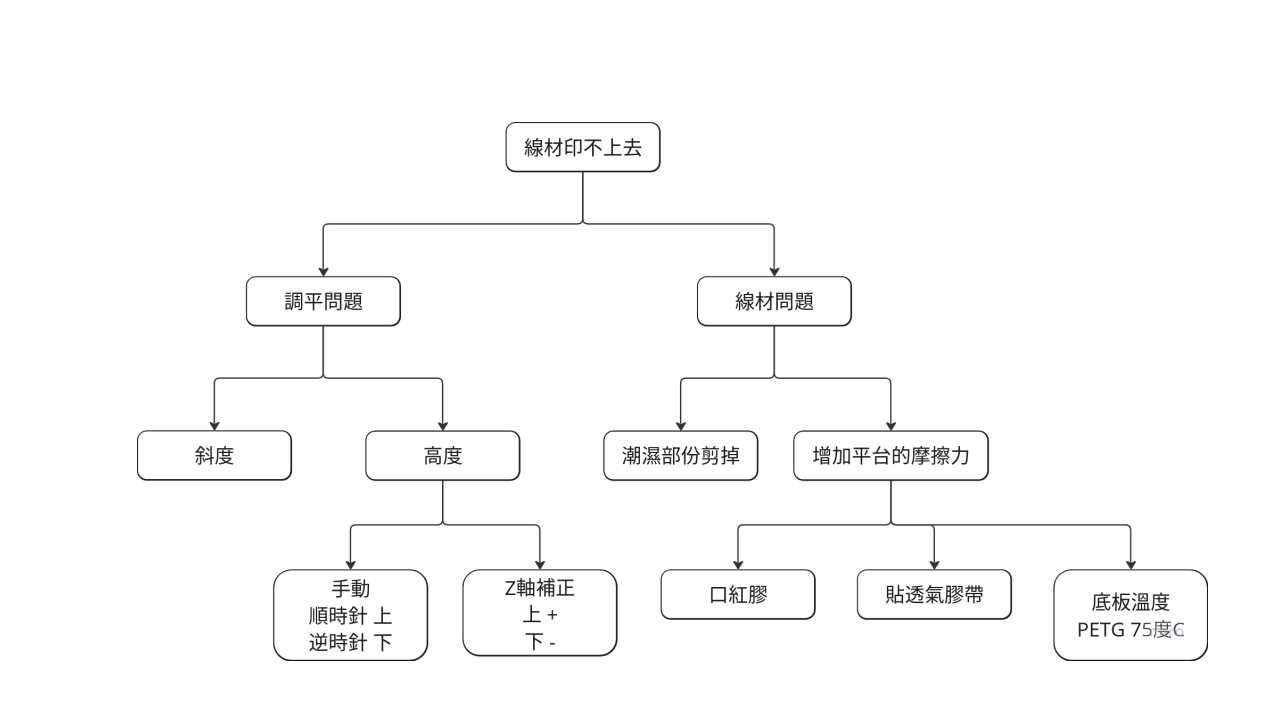
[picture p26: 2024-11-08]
behavior_box_3Dprint_models_eddlai/debug_SOP.webp

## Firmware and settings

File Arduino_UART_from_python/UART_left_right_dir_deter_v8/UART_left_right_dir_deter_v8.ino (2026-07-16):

#include <Arduino.h>
#include <SoftwareSerial.h>
#include <Servo.h>

//----- 定義模式一的pin腳 -----
const int LED_R1 = 6; // 用於 Mode 1 的右側提示燈
const int LED_R2 = 7; 
const int LED_L1 = 12;
const int LED_L2 = 13;

// 伺服馬達
Servo reward_L; // 10 
Servo reward_R; // 9

// 三向筏角度控制
const int posClose = 0;   // 關門角度
const int posOpen = 180;  // 開門角度

int currentPosL = posClose; // 記錄左門當前角度 (initial)
int currentPosR = posClose; // 記錄右門當前角度 (initial)

//----- 定義模式二的pin腳 -----
const int pumpPin = 5;
const int ledPin = 7; // 用於 Mode 2 和 Mode 3 的給水提示燈(6,7)

//----- 通用變數 -----
char receivedChar; // 宣告字符變量
int mode = 0; // 模式選擇變量
int lastMode = 0; // 記錄上一次的模式，用於偵測模式切換
int trial = 0; // 計算當前的trial次數

bool isObstacle_M = false;  // IR sensor(中路)初始狀態
bool isObstacle_L = false;  // true when left correct response
bool isObstacle_R = false;  // true when right correct response
int ans = 0;  // 暫存此次trial應給水的位置
int reward_time = 300;
int reward_time_R = 450;
int reward_time_L = 150;
bool taskInProgress = false;

// 閃爍時仍可能延遲太久 導致下一個 L/R 指令在 loop 中被讀走但無法處理
// 非阻塞閃爍相關變數
bool blinking = false;
unsigned long blinkLastToggle = 0;
int blinkCount = 0;
int blinkState = 0;
int led1 = 0, led2 = 0;
const int maxBlinks = 15;

SoftwareSerial MySerial(2, 3); // RX, TX

// 函數宣告
void blinkLed(int duration, int blinkDelay);
void left_right();
// void stand_up();
void manual_mode();
void drain_mode();
void long_locomotion();
void resetState();
void processResponse(char response);
void moveServoSmooth(Servo &s, int from, int to);

void setup() {
  MySerial.begin(115200);
  Serial.begin(115200); // 初始化USB串口

  // 設置模式一的pin腳模式
  reward_L.attach(10);  // left signal from pin 10
  reward_R.attach(9); // right signal from pin 9
  pinMode(LED_L1, OUTPUT);
  pinMode(LED_L2, OUTPUT);
  pinMode(LED_R1, OUTPUT);
  pinMode(LED_R2, OUTPUT);

  // 設置模式二的pin腳模式
  pinMode(pumpPin, OUTPUT);
  pinMode(ledPin, OUTPUT);

  // 初始化為非激活狀態（改為 180 度伺服馬達的初始關門位置）
  currentPosL = posClose; 
  currentPosR = posClose;
  reward_L.write(currentPosL);
  reward_R.write(currentPosR);
  digitalWrite(pumpPin, HIGH);
  digitalWrite(ledPin, LOW);

  // Serial.println(F("Ready"));
  // Serial.println(F("========================================="));
  Serial.println(F(" System Ready! Please select a mode: "));
  Serial.println(F(" Enter '1' : Camera detection mode"));
  Serial.println(F(" Enter '2' : Standup (Auto Interval) mode (Right Door)"));
  Serial.println(F(" Enter '3' : Manual Control mode"));
  Serial.println(F(" Enter '4' : Drain mode"));
  Serial.println(F(" Enter '5' : Long locomotion mode (L/R point -> reward)"));
  // Serial.println(F("========================================="));
  
  // 等待用戶輸入模式選擇
  // before Serial.read, Serial.available()=0
  while (Serial.available() == 0) {
    // 等待用戶輸入
  }
  receivedChar = Serial.read();
  if (receivedChar == '1') {
    mode = 1;
    Serial.println(F("-> [Mode 1] Camera detection mode selected"));

  } else if (receivedChar == '2') {
    mode = 2;
    Serial.println(F("-> [Mode 2] Standup mode selected"));
    Serial.println(F("    Random Time Interval (Auto), open only Right Door"));

  } else if (receivedChar == '3') {
    mode = 3;
    Serial.println(F("-> [Mode 3] Manual Control mode selected"));
    Serial.println(F("   Tutorial: Enter '1' to OPEN/BLINK, '0' to CLOSE/STOP)"));
  
  } else if (receivedChar == '4') {
    mode = 4;
    Serial.println(F("-> [Mode 4] Drain mode selected"));

  } else if (receivedChar == '5') {
    mode = 5;
    Serial.println(F("-> [Mode 5] Long locomotion mode selected"));
    Serial.println(F("    L point -> left reward, R point -> right reward"));

  } else {
    Serial.println(F("Invalid mode selected. Defaulting to Camera detection mode."));
    mode = 1;
  }
}

void loop() {
  // 偵測模式切換，在切換時處理伺服馬達
  if (mode != lastMode) {
    if (mode == 1 || mode == 5) {
      // 切換到需要雙門的模式時，重新連接伺服馬達並設為當前角度
      reward_L.attach(10);
      reward_R.attach(9);
      reward_L.write(currentPosL);
      reward_R.write(currentPosR);
    } else {
      // 切換到其他模式時 detach 伺服馬達以減少雜訊
      reward_L.detach();
      reward_R.detach();
    }
    lastMode = mode;
  }

  if (mode == 1) {
    left_right();
  // } 
  // else if (mode == 2) {
    // stand_up();
  } else if (mode == 3) {
    manual_mode();
  } else if (mode == 4) {
    drain_mode();
  } else if (mode == 5) {
    long_locomotion();
  }
}

///////////////// left right mode (Mode 1) /////////////////////
void left_right() {
  // 累積指令進 buffer
  while (MySerial.available() > 0) {
    char rat_response = MySerial.read();
    processResponse(rat_response);  // 在閃爍中也會立即處理指令
  }

  // 處理 LED 閃爍狀態
  if (blinking) {
    unsigned long currentMillis = millis();
    if (currentMillis - blinkLastToggle >= 167) {
      blinkLastToggle = currentMillis;
      blinkState = !blinkState;

      if (blinkState) {
        digitalWrite(led1, HIGH);
        digitalWrite(led2, LOW);
      } else {
        digitalWrite(led1, LOW);
        digitalWrite(led2, HIGH);
        blinkCount++;

        if (blinkCount >= maxBlinks) {
          digitalWrite(led1, LOW);
          digitalWrite(led2, LOW);
          blinking = false;
          Serial.println(F("LED blinking finished. Waiting for 'L' or 'R'."));
        }
      }
    }
  }
}

// 獨立處理每個指令 避免訊號重疊
void processResponse(char response){
  // 如果收到 'D'，立即停止所有操作
  if (response == 'D') {
    // op1-平滑關閉兩側的門
    moveServoSmooth(reward_L, currentPosL, posClose);
    moveServoSmooth(reward_R, currentPosR, posClose);
    // op2-瞬間關門
    // reward_L.write(posClose);
    // reward_R.write(posClose);

    // 更新當前角度紀錄
    currentPosL = posClose;
    currentPosR = posClose;

    Serial.println(F("Sudden stop received: Doors closed"));
    blinking = false;
    resetState();
    return;
  }

  // 如果碰到紅點 M 隨機決定任務方向
  if (response == 'M') {
    if (taskInProgress) {
      Serial.println(F("Task already in progress. Ignoring duplicate 'M'."));
      return; // 如果已有任務正在進行，忽略重複的 M
    }

    resetState();
    isObstacle_M = true; // 更改狀態
    taskInProgress = true;
    ans = random(1, 3); // 隨機決定方向: 1 是左邊、2 是右邊
    Serial.print(F("Red point detected. Task assigned: "));
    Serial.println((ans == 1) ? "Left" : "Right");

    // LED 閃爍 (啟動非阻塞閃爍)
    blinking = true;
    blinkLastToggle = millis();
    blinkCount = 0;
    blinkState = 0;
    led1 = (ans == 1) ? LED_L1 : LED_R1;
    led2 = (ans == 1) ? LED_L2 : LED_R2;
    return;
  }

  // 接收到 L / R 回應
  if (isObstacle_M) {
    if (response == 'R' && ans == 2 && !isObstacle_R) {
      // 正確走右邊
      Serial.println(F("Right signal received: Correct side"));
      isObstacle_R = true;
      blinking = false;

      // 平滑開啟右門
      Serial.println(F("right door opening..."));
      moveServoSmooth(reward_R, currentPosR, posOpen);
      currentPosR = posOpen;
      
      delay(reward_time); // 等待給水/獎勵時間
      
      // 平滑關閉右門
      Serial.println(F("right door closing..."));
      moveServoSmooth(reward_R, currentPosR, posClose);
      currentPosR = posClose;
      
      Serial.println(F("right reward finish"));
      resetState(); // 重置狀態

    } else if (response == 'L' && ans == 1 && !isObstacle_L) {
      // 正確走左邊
      Serial.println(F("Left signal received: Correct side"));
      isObstacle_L = true;
      blinking = false;

      // 平滑開啟左門
      Serial.println(F("left door opening..."));
      moveServoSmooth(reward_L, currentPosL, posOpen);
      currentPosL = posOpen;
      
      delay(reward_time); // 等待給水/獎勵時間
      
      // 平滑關閉左門
      Serial.println(F("left door closing..."));
      moveServoSmooth(reward_L, currentPosL, posClose);
      currentPosL = posClose;
      
      Serial.println(F("left reward finish"));
      resetState();

    } else if (response == 'R' && ans == 1) {
      // 走錯了，應該走左邊
      Serial.println(F("Right signal received: Wrong side, expected Left"));
      blinking = false;
      resetState();
    } else if (response == 'L' && ans == 2) {
      // 走錯了，應該走右邊
      Serial.println(F("Left signal received: Wrong side, expected Right"));
      blinking = false;
      resetState();
    }
  }
}

// 重置狀態
void resetState() {
  isObstacle_M = false;
  isObstacle_L = false;
  isObstacle_R = false;
  ans = 0;
  taskInProgress = false;
  blinking = false;
  digitalWrite(led1, LOW);
  digitalWrite(led2, LOW);
}

// 平滑移動函式：讓馬達以指定的步進角度緩慢轉動，避免瞬間全速扯動機構
void moveServoSmooth(Servo &s, int from, int to) {
  if (from == to) {
    return; // 如果起點和終點一樣（門已經在目標位置），直接結束函式
  }
  
  if (from < to) { 
    // 若目標角度大於當前角度 (正轉)
    for (int a = from; a <= to; a += 5) {
      s.write(a);
      delay(10); 
    }
  } else { 
    // 若目標角度小於當前角度 (反轉)
    for (int a = from; a >= to; a -= 5) {
      s.write(a);
      delay(10);
    }
  }
}

///////////////// long locomotion mode (Mode 5) /////////////////////
// 碰到 L / R 點就直接給水（開對應側的門），不需要 M 觸發、不判斷對錯。
// 防重複機制：給一次水後上鎖(disarm)，必須走過黑點('D')才會重新武裝(rearm)。
// armed 為 L/R 共用的單一鎖；初始為 true，所以第一次碰 L/R 就會給水。
void long_locomotion() {
  static bool armed = true; // true=可觸發給水；false=已給水，等待黑點 'D' 解鎖

  while (MySerial.available() > 0) {
    char rat_response = MySerial.read();

    if (rat_response == 'D') {
      // 走過任一黑點(MD/LD/RD)：重新武裝，允許下一次 L/R 給水
      if (!armed) {
        armed = true;
        Serial.println(F("[Mode 5] Black point passed: rearmed"));
      }

    } else if (rat_response == 'L' && armed) {
      // 碰到左邊點且處於武裝狀態：開左門給水，然後上鎖
      armed = false; // 給水前先上鎖，阻塞期間湧入的重複 L/R 會被忽略
      Serial.println(F("[Mode 5] Left point reached: left reward (disarmed)"));
      moveServoSmooth(reward_L, currentPosL, posOpen);
      currentPosL = posOpen;

      delay(reward_time_L); // 給水/獎勵時間

      moveServoSmooth(reward_L, currentPosL, posClose);
      currentPosL = posClose;
      Serial.println(F("left reward finish"));

    } else if (rat_response == 'R' && armed) {
      // 碰到右邊點且處於武裝狀態：開右門給水，然後上鎖
      armed = false;
      Serial.println(F("[Mode 5] Right point reached: right reward (disarmed)"));
      moveServoSmooth(reward_R, currentPosR, posOpen);
      currentPosR = posOpen;

      delay(reward_time_R); // 給水/獎勵時間

      moveServoSmooth(reward_R, currentPosR, posClose);
      currentPosR = posClose;
      Serial.println(F("right reward finish"));
    }
    // 其他情況（已 disarmed 的 L/R、或未定義字元）：讀掉丟棄，不作動
  }
}

///////////////// stand up mode (Mode 2) /////////////////////
// void stand_up() {
//   reward_R.attach(9);

//   Serial.println(F("Stand-up: Right door opening..."));
//   moveServoSmooth(reward_R, currentPosR, posOpen);
//   currentPosR = posOpen;

//   // 閃爍LED燈, 持續6秒, 每次閃爍間隔500毫秒 (這 6 秒期間，右門會維持開啟狀態給水)
//   Serial.println(F("Blink every 500ms for 6sec"));
//   blinkLed(6, 500);            

//   Serial.println(F("Stand-up: Right door closing..."));
//   moveServoSmooth(reward_R, currentPosR, posClose);
//   currentPosR = posClose;

//   digitalWrite(ledPin, LOW);

//   // 5. 斷開右邊馬達以減少待機時的雜訊與抖動
//   reward_R.detach();

//   // 6. 隨機間隔時間
//   long interval = random(20000, 35000);  // 從20秒到35秒的隨機間隔
//   Serial.print(F("Stand-up: Waiting for next trial ("));
//   Serial.print(interval / 1000);
//   Serial.println(F(" s)..."));
//   delay(interval);
// }

///////////////// Manual Control mode (Mode 3) /////////////////////
void manual_mode() {
  // 使用靜態變數來記憶當前的狀態，這些變數在迴圈中不會被重置
  static bool isManualActive = false;     // 記錄目前是否處於「正在給水/閃燈」的狀態
  static unsigned long lastBlinkTime = 0; // 記錄上一次切換燈號的時間
  static bool ledState = LOW;             // 記錄目前的燈號是亮還是暗

  // 1. 處理你的鍵盤輸入
  while (Serial.available() > 0) {
    char c = Serial.read();

    // 忽略換行與空白
    if (c == '\n' || c == '\r' || c == ' ' || c == '\t') continue;

    if (c == '1') {
      // 只有在「本來是關閉狀態」時按 1 才作動，避免重複按 1 造成馬達抽動
      if (!isManualActive) {
        Serial.println(F("Manual Switch: Right door OPEN & Blinking START"));
        isManualActive = true;
        
        // 重新連接馬達並開門
        reward_R.attach(9);
        moveServoSmooth(reward_R, currentPosR, posOpen);
        currentPosR = posOpen;
        
        // 初始化閃爍狀態 (馬上亮燈)
        ledState = HIGH;
        digitalWrite(ledPin, ledState);
        lastBlinkTime = millis();
      }

    } else if (c == '0') {
      // 只有在「本來是開啟狀態」時按 0 才作動
      if (isManualActive) {
        Serial.println(F("Manual Switch: Right door CLOSE & Blinking STOP"));
        isManualActive = false;
        
        // 強制關閉 LED 燈
        ledState = LOW;
        digitalWrite(ledPin, LOW);
        
        // 確保馬達有連線，然後平滑關門
        reward_R.attach(9);
        moveServoSmooth(reward_R, currentPosR, posClose);
        currentPosR = posClose;
        
        // 關門後斷開馬達以減少雜訊
        reward_R.detach();
      }

    } else {
      // 非 0/1 指令：忽略並回報
      Serial.print(F("Ignored input: "));
      Serial.println(c);
    }
  }

  // 2. 非阻塞式持續閃燈邏輯 (只要狀態是啟動的，就會自動在背景閃爍)
  if (isManualActive) {
    // 檢查是否已經過了 500 毫秒
    if (millis() - lastBlinkTime >= 500) { 
      lastBlinkTime = millis();            // 更新時間
      ledState = !ledState;                // 反轉燈號狀態 (亮變暗、暗變亮)
      digitalWrite(ledPin, ledState);      // 寫入燈號
    }
  }
}

// 閃爍LED燈函數
void blinkLed(int duration, int blinkDelay) {
  long endTime = millis() + duration * 1000;
  while (millis() < endTime) {
    digitalWrite(ledPin, HIGH);  // 打開LED燈
    delay(blinkDelay);            // 等待
    digitalWrite(ledPin, LOW);   // 關閉LED燈
    delay(blinkDelay);            // 等待
  }
}

///////////////// drain mode (Mode 4) /////////////////////
void drain_mode() {
  // 使用 static 變數，確保提示選單只會印出一次
  static bool menuPrinted = false;

  if (!menuPrinted) {
    Serial.println(F("========================================="));
    Serial.println(F(" Drain mode activated."));
    Serial.println(F(" Enter 'O' to OPEN doors and start draining."));
    Serial.println(F(" Enter 'C' to CLOSE doors and detach motors."));
    Serial.println(F("========================================="));
    menuPrinted = true; // 標記為已列印
  }

  // 持續監聽鍵盤輸入
  if (Serial.available() > 0) {
    char cmd = Serial.read();
    
    // 忽略換行與空白符號
    if (cmd == '\n' || cmd == '\r' || cmd == ' ' || cmd == '\t') {
      return; 
    }

    // 輸入 'O' 或 'o' 開門
    if (cmd == 'O' || cmd == 'o') {
      // 重新連接馬達
      reward_L.attach(10);
      reward_R.attach(9);
      
      Serial.println(F("-> Doors OPENING... Water is draining."));
      moveServoSmooth(reward_L, currentPosL, posOpen);
      moveServoSmooth(reward_R, currentPosR, posOpen);
      currentPosL = posOpen;
      currentPosR = posOpen;
    } 
    // 輸入 'C' 或 'c' 關門
    else if (cmd == 'C' || cmd == 'c') {
      Serial.println(F("-> Doors CLOSING..."));
      moveServoSmooth(reward_L, currentPosL, posClose);
      moveServoSmooth(reward_R, currentPosR, posClose);
      currentPosL = posClose;
      currentPosR = posClose;
      
      // 關門後斷開馬達以減少雜訊
      reward_L.detach();
      reward_R.detach();
      Serial.println(F("-> Doors are closed and motors detached. Safe to idle."));
    } 
    // 輸入其他無效字元
    else {
      Serial.print(F("Invalid command: "));
      Serial.println(cmd);
    }
  }
}

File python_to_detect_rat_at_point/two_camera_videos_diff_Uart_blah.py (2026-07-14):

# -*- coding: utf-8 -*-
import cv2
import os
import numpy as np
import serial
import time
import pickle

PORT = 'ttyUSB0' #origin: COM6
show = True
camera_number1 = 2
camera_number2 = 0
update = 0 #about baseline
#path
now_path = os.getcwd()
baseline_save_path = now_path + "/baseline"
baseline_pkl_save_path = now_path + "/baseline.pkl"
circles_pkl_save_path = "circles_posi.pkl"

# 初始化串口
def send_signal_to_arduino(port, baudrate, message):
    try:
        # 初始化Serial物件
        ser = serial.Serial(port, baudrate, timeout=1)
        print(f"Connected to {port} at {baudrate} baud")

        # 發送訊號
        ser.write(message.encode())
        print(f"Sent message: {message}")

        # 延遲以確保訊號傳輸完成
        time.sleep(0.02)

        # 關閉Serial通訊
        ser.close()
        print("Connection closed")

    except serial.SerialException as e:
        print(f"Error: {e}")

def take_baseline():
    baseline_save_path = "baseline"
    "======================================="
    baseline_save_path = now_path+r'/{}'.format(baseline_save_path)
    # baseline_save_path= "/home/yylab/Desktop/camera_detect/baseline"


    try:
        os.chdir(baseline_save_path)
        print("資料夾已存在:", baseline_save_path)
    except FileNotFoundError:
        try:
            os.makedirs(baseline_save_path)
            os.chdir(baseline_save_path)
            print("成功創建資料夾:", baseline_save_path)
        except Exception as e:
            print("無法創建或訪問資料夾:", e)
            
    checkpoint_x_1_cam1 = 400
    checkpoint_y_1_cam1 = 0
    checkpoint_x_1_cam2 = 400
    checkpoint_y_1_cam2 = cut_stop

    cap1 = cv2.VideoCapture(camera_number1)
    print("0號相機啟動")
    cap2 = cv2.VideoCapture(camera_number2)
    print("1號相機啟動")

    now = 0
    while now < 30:
        ret0, frame1 = cap1.read()
        ret1, frame2 = cap2.read()
        now = now + 1

    now = 0
    while now < 120:
        ret0, frame1 = cap1.read()
        ret1, frame2 = cap2.read()
        
        combine_videos = np.concatenate((frame2[cut_start:cut_stop,:,:], frame1), axis=0)
        cv2.imwrite(baseline_save_path + r"/" + str(now) + ".jpg", combine_videos)
        cv2.imshow('combine', combine_videos)
        now = now + 1
        if cv2.waitKey(1) & 0xFF == ord('q'):
            break
        
    cap1.release()
    cap2.release()
    cv2.destroyAllWindows()

def get_mouse_coord(event, x, y, flags, param):
    if event == cv2.EVENT_LBUTTONDOWN:
        print("at ({},{})".format(x,y))
        mouse_x, mouse_y = x, y
        circle_pos_list[index][1] = mouse_x
        circle_pos_list[index][2] = mouse_y
        
def printCircles(frame, circle_list): # circle_list = circle_pos_list
    # cv2.circle(img, center position, radius, color)
    cv2.circle(frame, (circle_list[0][1], circle_list[0][2]), 25, (0, 0, 255), -1) #red  (M)
    cv2.circle(frame, (circle_list[1][1], circle_list[1][2]), 15, (255, 0, 0), -1) #blue (L)
    cv2.circle(frame, (circle_list[2][1], circle_list[2][2]), 15, (0, 255, 0), -1) #green(R)
    cv2.circle(frame, (circle_list[3][1], circle_list[3][2]), 15, (0, 0, 0), -1)   #black1 (MD)
    cv2.circle(frame, (circle_list[4][1], circle_list[4][2]), 15, (0, 0, 0), -1)   #black2 (LD)
    cv2.circle(frame, (circle_list[5][1], circle_list[5][2]), 15, (0, 0, 0), -1)   #black3 (RD)
    cv2.circle(frame, (circle_list[6][1], circle_list[6][2]), 15, (0, 0, 0), -1)   #black4 (XD)

def pin_output_ifs(x, y, distance_from_target=40):
    if np.abs(x - circle_pos_list[0][1]) < distance_from_target and np.abs(y - circle_pos_list[0][2]) < distance_from_target:
        send_signal_to_arduino(PORT, 115200, 'M')
        print("Middle cue")
            
    elif np.abs(x - circle_pos_list[1][1]) < distance_from_target and np.abs(y - circle_pos_list[1][2]) < distance_from_target:
        send_signal_to_arduino(PORT, 115200, 'L')
        print("Left cue")
    
    elif np.abs(x - circle_pos_list[2][1]) < distance_from_target and np.abs(y -circle_pos_list[2][2]) < distance_from_target:
        send_signal_to_arduino(PORT, 115200, 'R')
        print("Right cue")
        
    elif np.abs(x - circle_pos_list[5][1]) < distance_from_target and np.abs(y - circle_pos_list[5][2]) < distance_from_target:
        send_signal_to_arduino(PORT, 115200, 'D')
        print("RD")

    elif np.abs(x - circle_pos_list[6][1]) < distance_from_target and np.abs(y - circle_pos_list[6][2]) < distance_from_target:
        send_signal_to_arduino(PORT, 115200, 'D')
        print("XD")
    
    elif np.abs(x - circle_pos_list[4][1]) < distance_from_target and np.abs(y - circle_pos_list[4][2]) < distance_from_target:
        send_signal_to_arduino(PORT, 115200, 'D')
        print("LD")
            
    elif np.abs(x - circle_pos_list[3][1]) < distance_from_target and np.abs(y - circle_pos_list[3][2]) < distance_from_target:
        send_signal_to_arduino(PORT, 115200, 'D')
        print("MD")
    else:
        pass
        
def cal_baseline(file_path):
    baseline_file = os.listdir(file_path)
    combine_baseline = np.array(np.zeros((480 + cut_stop, 640, 3)))
    count = 0
    print("計算baseline平均")
    for i in baseline_file:
        print(file_path + "/" + i)
        img = cv2.imread(file_path + "/" + i)
        combine_baseline = combine_baseline + img
        count = count + 1

    baseline_avg = np.array((combine_baseline/count), dtype=np.uint8)
    baseline_img_gray = cv2.cvtColor(baseline_avg, cv2.COLOR_BGR2GRAY)
    return baseline_img_gray

"========================================="

global circle_pos_list
try:
    with open(circles_pkl_save_path, "rb") as file:
        circle_pos_list = pickle.load(file)
except FileNotFoundError:
    print("no recoreded circles' positions, use default setting")
    target_M_x = 50 # red qiu qiu
    target_M_y = 50
    target_L_x = 100 # blue qiu qiu
    target_L_y = 100
    target_R_x = 150 # green qiu qiu
    target_R_y = 150
    target_MD_x = 200 # black qiu qiu 1
    target_MD_y = 200
    target_LD_x = 250 # black qiu qiu 2
    target_LD_y = 250
    target_RD_x = 300 # black qiu qiu 3
    target_RD_y = 300
    target_XD_x = 350 # black qiu qiu 4
    target_XD_y = 350
    circle_pos_list = [["M", target_M_x, target_M_y], ["L", target_L_x, target_L_y], ["R", target_R_x, target_R_y], ["MD", target_MD_x, target_MD_y], ["LD", target_LD_x, target_LD_y], ["RD", target_RD_x, target_RD_y], ["XD", target_XD_x, target_XD_y]]

cut_start = 0
cut_stop = 435

try:
    with open(baseline_pkl_save_path, "rb") as file:
        print(baseline_pkl_save_path)
        baseline_img_gray = pickle.load(file)
        exist = True
except FileNotFoundError:
    exist = False
    
if not exist or update:
    with open(baseline_pkl_save_path, "wb") as file:
        take_baseline()
        print(baseline_save_path)
        baseline_img_gray = cal_baseline(baseline_save_path)
        pickle.dump(baseline_img_gray, file)
        print("new baseline saved")
else:
    print("old baseline loaded")

kernel = np.ones((7, 7), np.uint8)
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

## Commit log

2024-11-25 add standup time fixed mode and turning correct response rewards
    [UART_left_right_dir_deter_blah_altertime.ino, UART_left_right_dir_deter_blah_correct_reward.ino, two_camera_videos_diff_Uart_blah.py]
2024-11-30 UART Arduino v3 detect to wrong point but no restate solved
2025-03-24 Resolved the lag problem from receiving new commands while flashing, complete stand mode and left/right mode.
    [UART_left_right_dir_deter_v3.ino, UART_left_right_dir_deter_v4.ino, two_camera_videos_diff_Uart_blah.py]
2025-03-24 Rename file UART_lr_blah3.ino to UART_lr_v3.ino
2026-01-14 add v5(servo) and function update introduction
2026-01-16 remove .claude and add motor test
2026-01-30 Update README with current operating version details
    Added current operating version section with links to Arduino and Python files.
2026-04-01 Update servo motor versions in README
2026-04-02 feat: implement smooth 3-way valve control and refactor experiment modes
    - Hardware: Integrated 180-degree servo for 3-way valve precise positioning.
    - Control: Added moveServoSmooth for smooth gear/valve stepping to reduce mechanical noise.
    - Mode 2 (Auto Stand-up): Refactored to right-door only with synchronized dual LED cues.
    - Mode 3 (Manual Control): Replaced fixed-interval with true manual toggle ('1' to open/blink, '0' to close).
    - Mode 4 (Drain Mode): Added new maintenance mode to open both doors for water drainage.
    - Clean-up: Removed deprecated interval calculation functions and variables.
    [UART_left_right_dir_deter_v5.ino, UART_left_right_dir_deter_v7.ino]
2026-06-11 add gear 3dprint file
    [Copy of Gear.stl]
